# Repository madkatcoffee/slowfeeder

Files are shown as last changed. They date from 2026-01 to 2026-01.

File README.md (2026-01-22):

# Madkat Feedr - A 3D printable and solder-free DIY slow feeder by Madkat Coffee

Free to download, 3d print and build, battery-powered slow feeder for coffee grinders

A simple, fast-to-build slow feeder to help you test and experience the impact of controlled bean feeding on grind consistency and extraction.

This project is intended as a learning and experimentation tool.
If you want a set-and-forget, variable-speed, daily-use version, see the metal upgrade at www.madkatcoffee.com.

## Why slow feeding?

Slow feeding:

Reduces fines generation

Reduces heat generation

Improves shot to shot consistency with a motorized feeder

## Many users report:

Improved clarity

Better flavour separation

Improved aroma

This DIY design exists so you can try it yourself.

## What this is (and isn’t)

### This is:

A simple ON/OFF slow feeder

Battery powered (2× AA)

Easy to print and assemble

Includes separate cassette wheels for feed speed reduction.

Designed to work with adapters that can be modified to suit your grinder. The included EK43 adapter has been included as a step file so you can modify/remix as you need to suit your grinder.

### This is not:

A variable speed feeder

A finished product

## Build overview

Build time: ~30–45 minutes

Print time: ~12 hours (depends on printer)

## Required tools

3D printer

Small screwdrivers

Wire strippers (to strip ends of wires)

## Files included

/STL/ – Printable parts (core assembly provided as STL)

/BOM/ – Bill of materials with sourcing notes

/Assembly/ – Step-by-step build instructions (PDF)

## You are free to:

Print

Build

Share

Remix

## Licensing

Core assembly: provided as-is for personal use

Funnels: open for remixing and sharing

## Known limitations

Fixed feed rate but can change with modified rotors.

Print quality matters (poor tolerances can cause fit issues)

Not designed for high-throughput or commercial use

For our variable speed product, you can find updates and availability at https://madkatcoffee.com

## Final note

This project exists because slow feeding has become a key part of our daily process for unlocking next level flavour and we want more people to experience it.

If you build one:

Post it on Instagram

Tag @madkatcoffee

We’ll feature the best builds and use community feedback to improve future designs.

Sign up to our newletter at www.madkatcoffee.com to be the first to hear about more community projects.

Remember, if you're making coffee at home you're already winning. So have fun with this build! Slow feeding is at the deeper end of the rabbit hole but the flavour improvement has been proven and confirmed by many leading coffee experts including Lance Hedrick, James Hoffman and Matt Perger at Barista Hustle.
 
Build it. Test it. Break it. Have fun with it!

—

Madkat Coffee

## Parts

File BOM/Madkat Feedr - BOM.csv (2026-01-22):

Quantity | Description | Make and Model/Sourcing
1 | N20 gear motor with wires | Amazon (https://www.amazon.com.au/XIITIA-3V-6V-Gearbox-Without-Terminal/dp/B0DZNRRTB1?th=1)
3 | M3x20mm countersunk screws | (generic)
3 | M3 nuts | (generic)
1 | ON/OFF Switch | (Judco 40-4526-00)
1 | Battery holder | (Keystone 2463)
1 | Wire splice | (Wago 221-412)
6 | 5mm Dia x 8mm Dia magnets | (AMF Magnetics C-D5H8-N35)

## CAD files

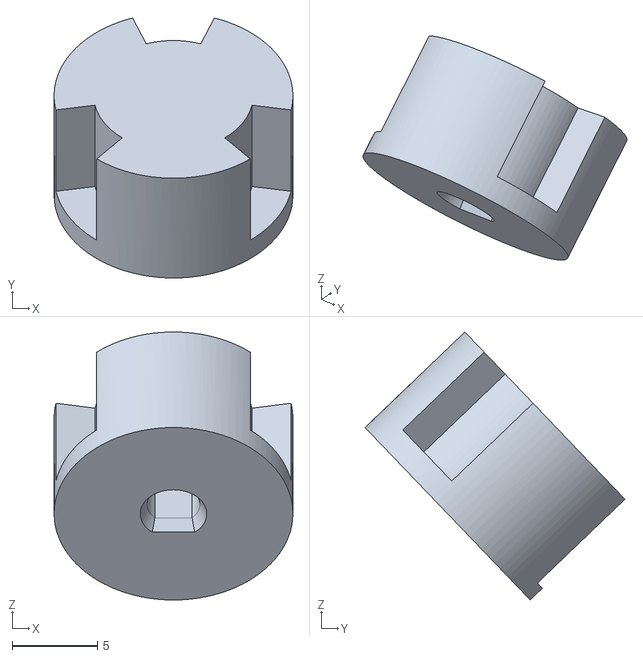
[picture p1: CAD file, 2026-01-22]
STL/Madkat Feedr_HubMain_v30.stl
14.0 x 15.2 x 15.7

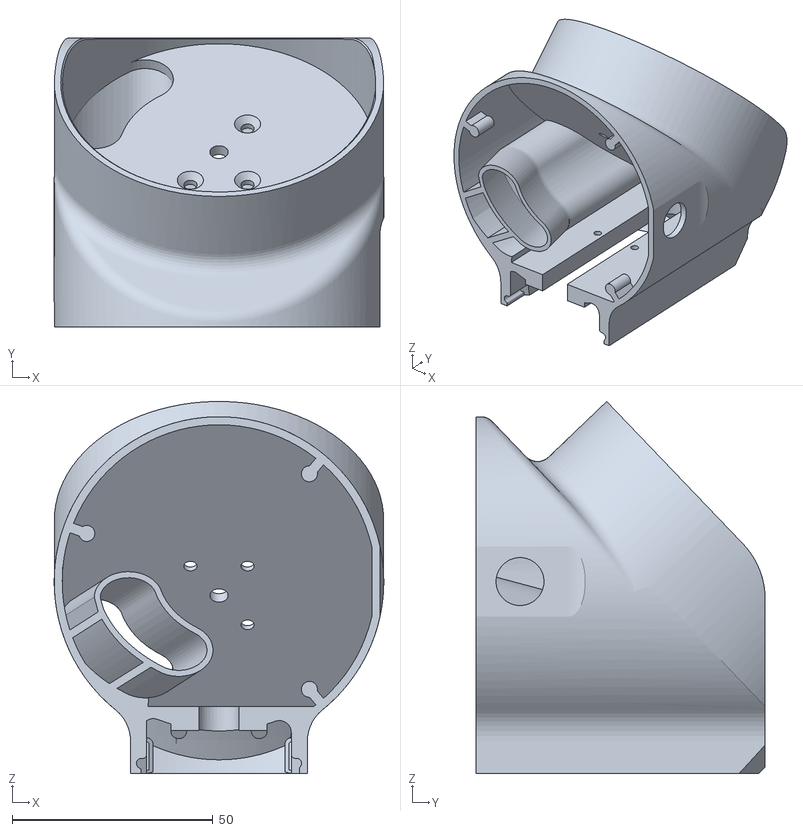
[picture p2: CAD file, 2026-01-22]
STL/Madkat Feedr_MainBody_v30.stl
82.0 x 72.0 x 92.5

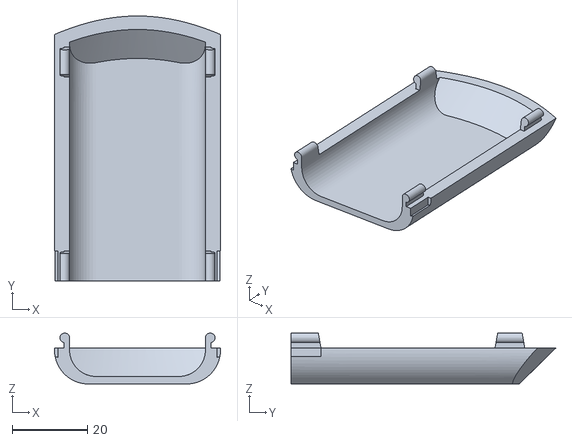
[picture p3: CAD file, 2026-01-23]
STL/Madkat Feedr_BatteryCover_v30.stl
44.0 x 70.2 x 13.5

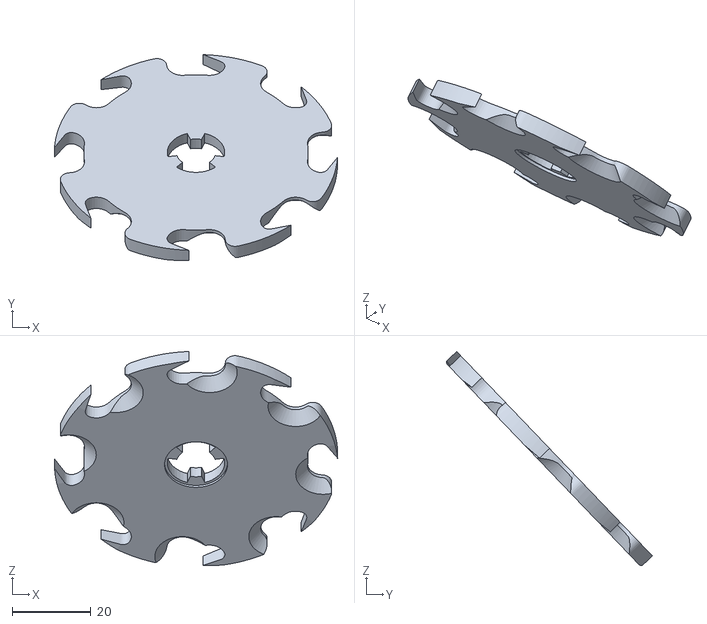
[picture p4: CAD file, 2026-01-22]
STL/Madkat Feedr_Rotor_v30.stl
71.9 x 52.3 x 54.3

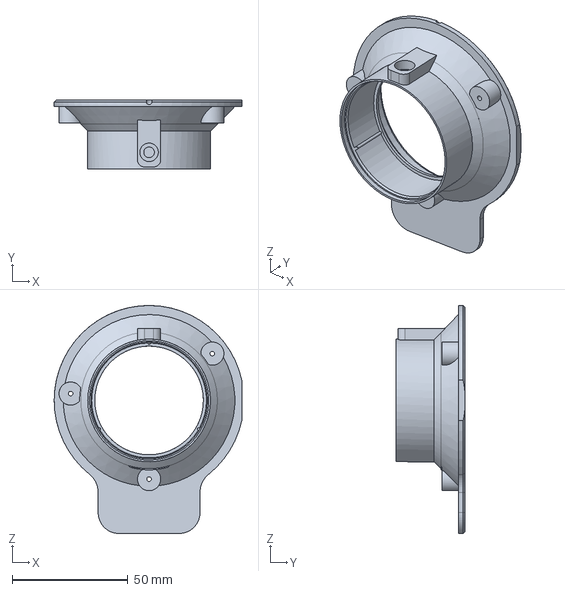
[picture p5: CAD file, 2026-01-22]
STL/Madkat Feedr_EK43_v5.step
81.1 x 30.0 x 98.5 mm

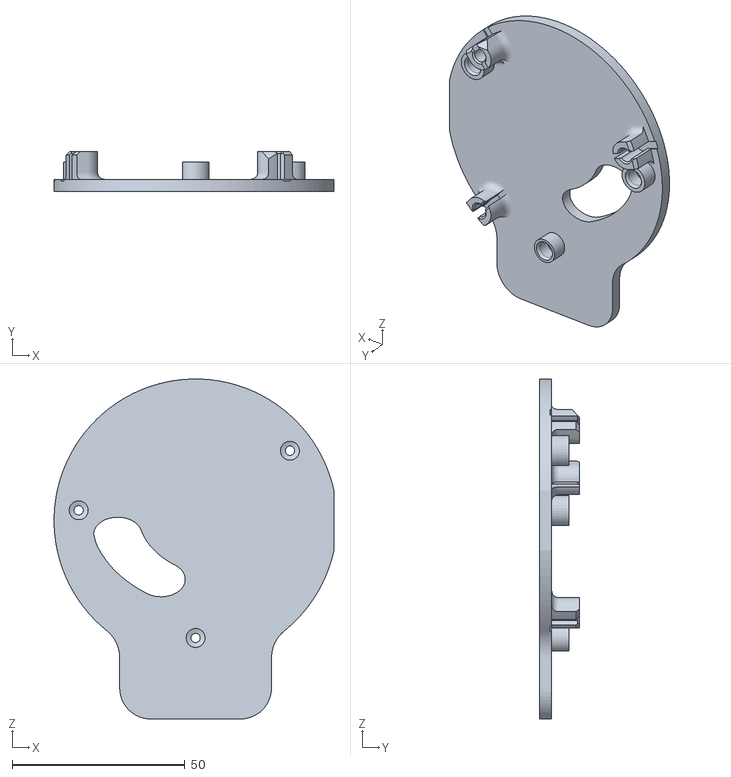
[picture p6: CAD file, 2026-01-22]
STL/Madkat Feedr_CaseBottom_v30.stl
81.1 x 11.5 x 98.5

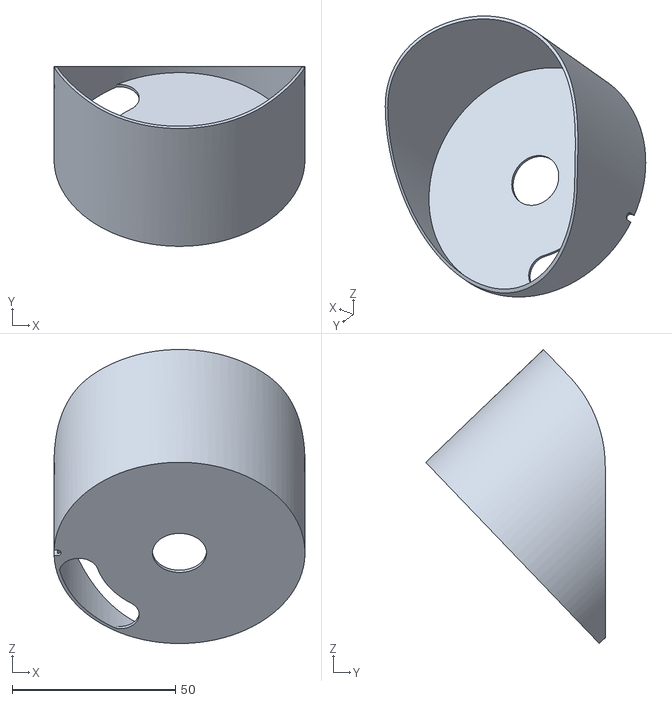
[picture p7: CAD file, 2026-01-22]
STL/Madkat Feedr_Insert_v30.stl
76.9 x 55.0 x 90.1

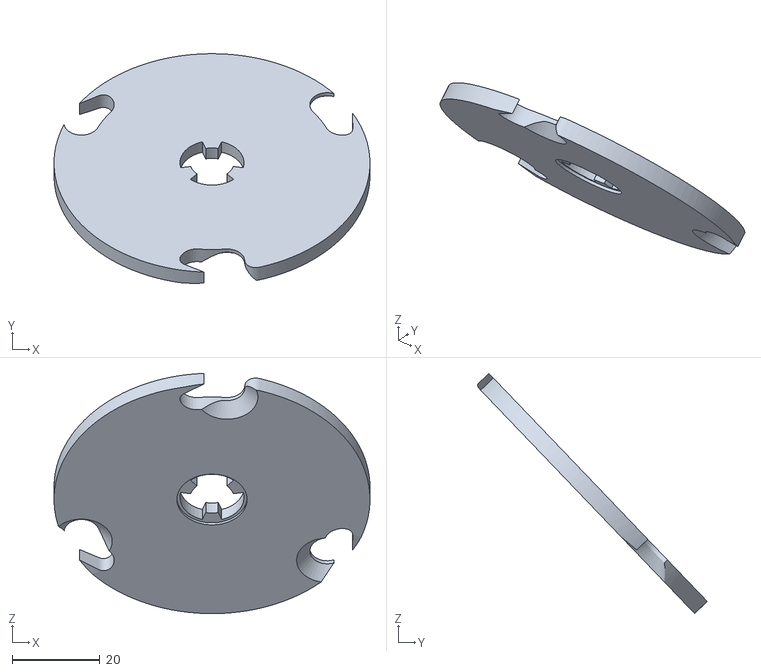
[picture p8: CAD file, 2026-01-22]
STL/Madkat Feedr_Rotor_3Slot_v30.stl
72.0 x 52.3 x 54.7

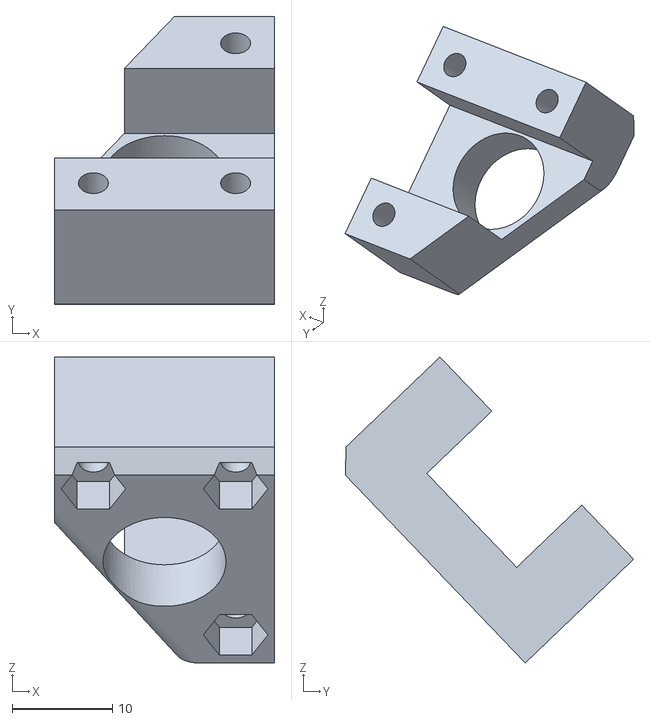
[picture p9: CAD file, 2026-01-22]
STL/Madkat Feedr_MotorMount_v30.stl
22.0 x 28.8 x 30.6

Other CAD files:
STL/Madkat Feedr_EK43 v5.stl

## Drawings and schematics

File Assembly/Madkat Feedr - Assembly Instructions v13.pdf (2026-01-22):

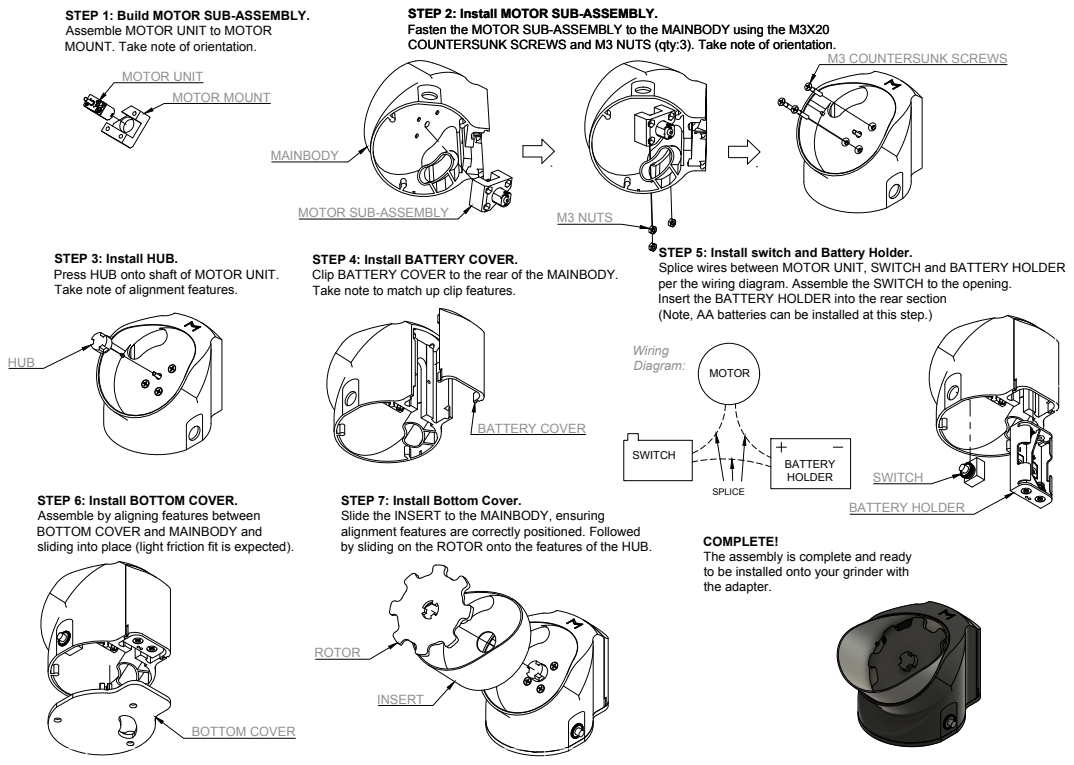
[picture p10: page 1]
MOTOR UNIT; MOTOR MOUNT; M3 NUTS; M3 COUNTERSUNK SCREWS; BATTERY COVER; BOTTOM COVER

STEP 1: Build MOTOR SUB-ASSEMBLY.
Assemble MOTOR UNIT to MOTOR
MOUNT. Take note of orientation.

STEP 2: Install MOTOR SUB-ASSEMBLY.
Fasten the MOTOR SUB-ASSEMBLY to the MAINBODY using the M3X20
COUNTERSUNK SCREWS and M3 NUTS (qty:3). Take note of orientation.

MOTOR SUB-ASSEMBLY

STEP 5: Install switch and Battery Holder.
Splice wires between MOTOR UNIT, SWITCH and BATTERY HOLDER
per the wiring diagram. Assemble the SWITCH to the opening.
Insert the BATTERY HOLDER into the rear section
(Note, AA batteries can be installed at this step.)

STEP 3: Install HUB.
Press HUB onto shaft of MOTOR UNIT.
Take note of alignment features.

STEP 4: Install BATTERY COVER.
Clip BATTERY COVER to the rear of the MAINBODY.
Take note to match up clip features.

BATTERY HOLDER STEP 6: Install BOTTOM COVER.
Assemble by aligning features between
BOTTOM COVER and MAINBODY and
sliding into place (light friction fit is expected).

STEP 7: Install Bottom Cover.
Slide the INSERT to the MAINBODY, ensuring
alignment features are correctly positioned. Followed
by sliding on the ROTOR onto the features of the HUB.

COMPLETE!
The assembly is complete and ready
to be installed onto your grinder with
the adapter.

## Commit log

2026-01-22 Initial commit with all files included.
    [MK Feedr DIY - BOM.csv, MK Feedr DIY_CaseBottom_v30.stl, MK Feedr DIY_HubMain_v30.stl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]
2026-01-22 Changed name to Madkat Feedr.
    [Madkat Feedr - BOM.csv, Madkat Feedr_CaseBottom_v30.stl, Madkat Feedr_EK43 v5.stl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]
2026-01-23 Added Battery Cover
    [Madkat Feedr_BatteryCover_v30.stl]
